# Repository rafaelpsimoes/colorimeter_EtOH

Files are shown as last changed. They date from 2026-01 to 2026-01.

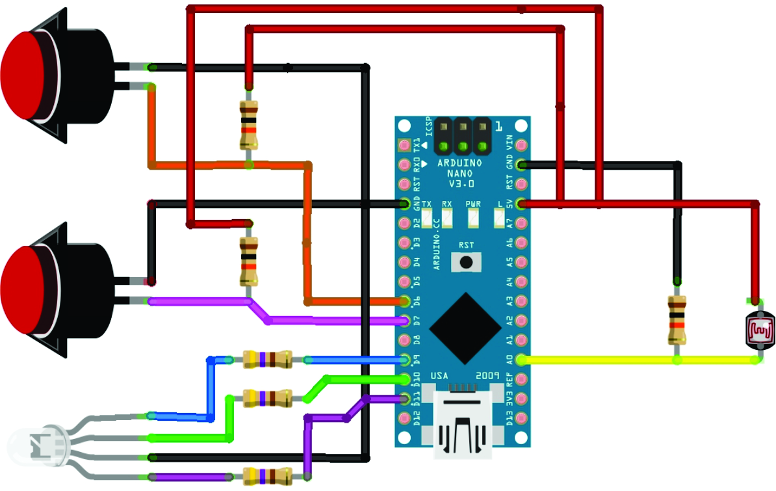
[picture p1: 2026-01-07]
hardware/schematics/schematic.jpg

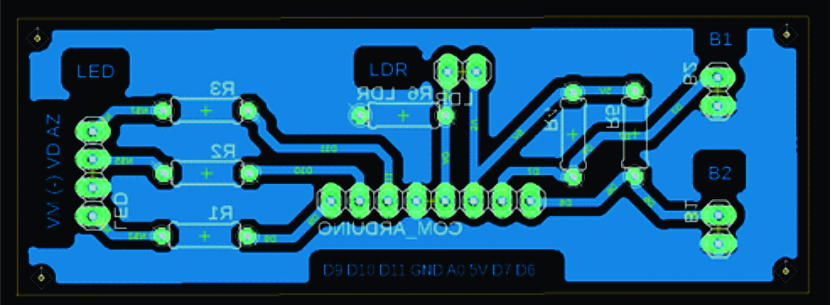
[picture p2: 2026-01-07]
hardware/pcb_eagle/eagle_mask.jpg

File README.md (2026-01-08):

# Low-Cost Portable Colorimeter for Indirect Ethanol Determination

This repository provides the complete set of hardware designs, firmware, and data-analysis scripts required to replicate the portable colorimeter described in the manuscript:

**Low-Cost Portable Colorimeter for Indirect Determination of Ethanol Concentration via Dichromate Oxidation**

The repository is intended to ensure **full reproducibility**, **methodological transparency**, and **low-cost accessibility**, in accordance with the scope and recommendations of *Hardware* (MDPI). All files necessary for device construction, operation, and data processing are made publicly available.

---

## Purpose and Scope

The proposed system is an open-hardware analytical device designed for indirect ethanol determination in aqueous solutions and simple beverage matrices. The instrument combines low-cost optical components, a microcontroller-based acquisition system, and open-source computational analysis to emulate spectrophotometric measurements in the visible range.

This repository supports:
- replication of the hardware design;
- execution of the firmware for data acquisition;
- processing of raw optical data into absorbance-like spectra;
- construction of calibration curves;
- estimation of ethanol concentration in unknown samples.

---

## Analytical Principle

Ethanol concentration is determined **indirectly** via its oxidation in acidic medium in the presence of potassium dichromate. The reduction of dichromate ions (Cr₂O₇²⁻) to Cr³⁺ produces a characteristic color change, with an absorption band centered around **595 nm**. Within the linear range of the method, the color intensity is proportional to the ethanol concentration.

**Important limitation:** the device does not measure ethanol directly. The analytical signal originates from the oxidation reaction products, and other oxidizable species may interfere depending on the sample matrix. This limitation is explicitly discussed in the associated manuscript.

---

## Repository Structure
├── hardware/  
│ ├── pcb_eagle/ # PCB layout designed using Autodesk Eagle (single-layer)  
│ ├── pcb_graphic/ # Alternative PCB mask with wider traces for ultra-low-cost fabrication  
│ ├── enclosure_stl/ # 3D-printable enclosure files (STL)  
│ └── schematics/ # Electronic schematics and wiring diagrams (PDF)  
│  
├── firmware/  
│ └── espec.ino # Arduino firmware for wavelength and transmittance acquisition  
│  
├── software/  
│ ├── etoh_concentrations.py # Calibration curve construction and spectral analysis  
│ ├── etoh_sample.py # Ethanol concentration estimation for unknown samples  
│ └── example_data/ # Example input files and formatting templates  
│  
├── documentation/  
│ └── assembly_guide # Device assembly illustrations  
│  
└── README.md  

---

## PCB Design Options and Fabrication Accessibility

Two functionally equivalent PCB layouts are provided to accommodate different fabrication constraints:

1. **Standard PCB layout (Eagle):**  
   Designed using Autodesk Eagle and optimized for compact integration and fabrication through conventional low-cost PCB manufacturing services.

2. **Graphic-mask PCB layout (wide traces):**  
   Developed using general-purpose graphic design software, featuring wider and more widely spaced conductive traces. This version facilitates ultra-low-cost fabrication approaches, such as manual toner transfer or direct printing, increasing robustness against fabrication defects.

Both PCB versions implement the same electronic circuit and were validated using the same experimental workflow.

---

## Operating Workflow Overview

### Step 1 — Sample Preparation
Prepare:
- a **blank solution** (0% ethanol), used as reference;
- ethanol standards covering the linear range of the method;
- unknown samples prepared according to the protocol described in the manuscript.

### Step 2 — Data Acquisition (Firmware)
1. Upload the firmware `firmware/espec.ino` to an Arduino-compatible board using the Arduino IDE.
2. Run the acquisition routine and open the Serial Monitor.
3. Copy the serial output (wavelength and transmittance values) and save it as plain text files.

### Step 3 — Required Input Files for Python Scripts

The Python scripts operate on plain text files containing wavelength–transmittance data:

- `ref.txt`  
  Reference measurement corresponding to the **blank (0% ethanol)**.

- Calibration files  
  One file per ethanol standard concentration (e.g., `0_5.txt`, `1_0.txt`, `1_5.txt`).

- Sample file(s)  
  Files corresponding to unknown samples (e.g., `sample_01.txt`).

Examples of correct file structure and formatting are provided in `software/example_data/`.

### Step 4 — Data Processing and Analysis
- `etoh_concentrations.py`  
  Converts transmittance to absorbance-like signals, performs spectral fitting, constructs calibration curves, and exports calibration parameters.

- `etoh_sample.py`  
  Applies calibration parameters to unknown samples and estimates ethanol concentration.

The scripts generate processed data tables and graphical outputs (spectra, calibration plots, and concentration results), consistent with the figures and tables presented in the manuscript.

---

## Validation and Performance

The portable colorimeter was validated by comparison with a commercial UV–Vis spectrophotometer. The results demonstrate linear calibration behavior (R² ≈ 0.99 within the tested range) and acceptable relative errors for alcoholic beverage samples analyzed under controlled conditions.

Detailed validation results and statistical analyses are presented in the associated publication.

---

## Safety Considerations

- Potassium dichromate and acidic solutions are hazardous chemicals.
- Appropriate personal protective equipment (PPE) must be used.
- Chromium-containing waste must be disposed of according to institutional and local regulations.

---

## Data and File Availability

All hardware designs, firmware, and software required to replicate the device and reproduce the experimental workflow are provided as supplementary materials and are available in this public repository:

**GitHub repository:** https://github.com/rafaelpsimoes/colorimeter_EtOH

---

## How to Cite

If you use this repository or any of its contents (hardware designs, firmware, or software), please cite the associated manuscript.  
A `CITATION.cff` file is included to facilitate citation export directly from GitHub.

---

## Intended Use

This repository is provided to support transparency, reproducibility, and academic use of the hardware and software described in the associated manuscript.

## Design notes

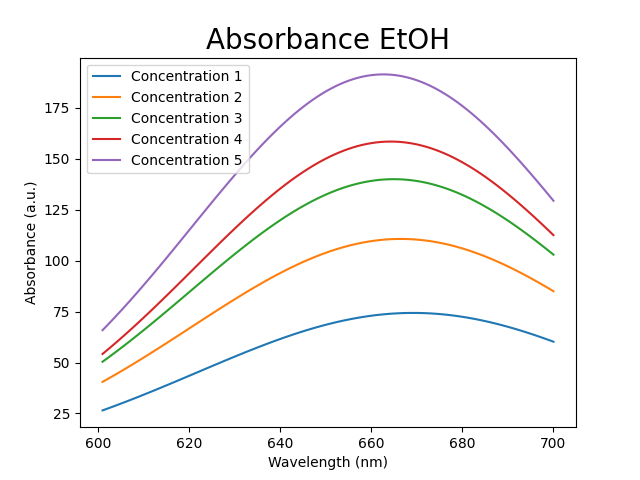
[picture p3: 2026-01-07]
software/example_data/absorbance_concentrations_clean.png

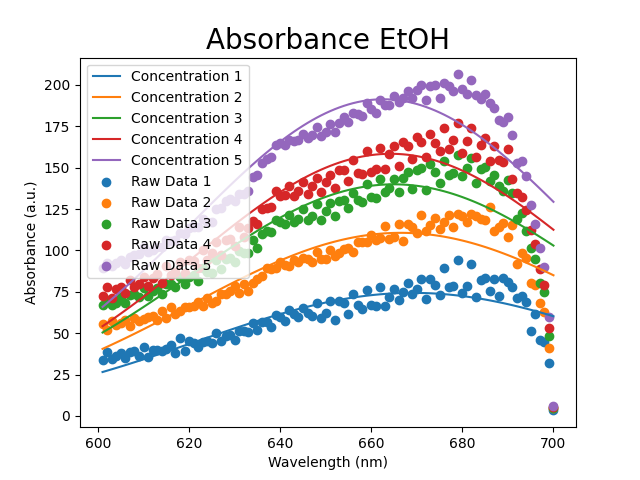
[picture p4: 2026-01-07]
software/example_data/absorbance_concentrations.png

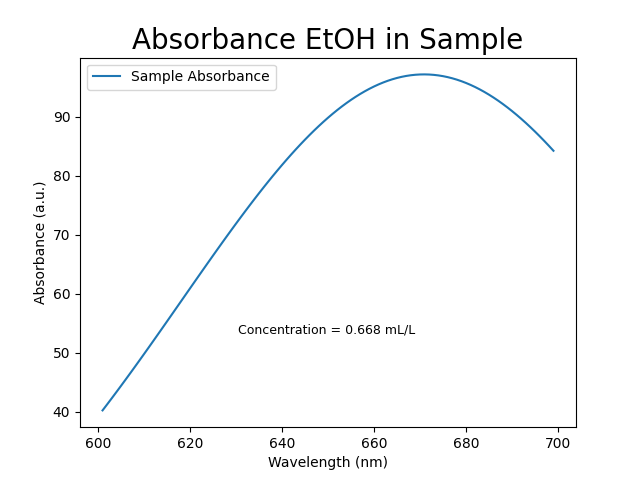
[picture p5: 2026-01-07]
software/example_data/absorbance_sample_vodka4.png

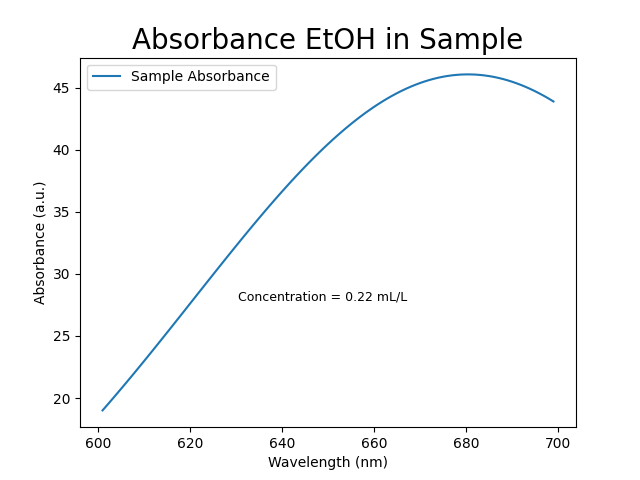
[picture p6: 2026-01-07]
software/example_data/absorbance_sample_vodka2.png

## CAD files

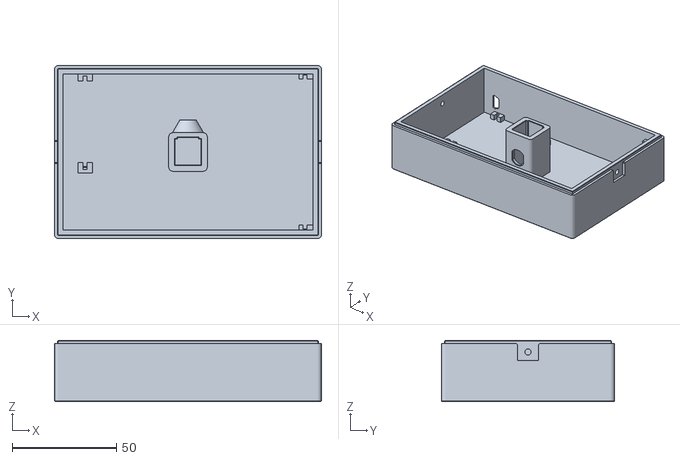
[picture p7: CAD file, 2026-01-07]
hardware/enclosure_stl/AL01.stl
128.0 x 83.0 x 29.2

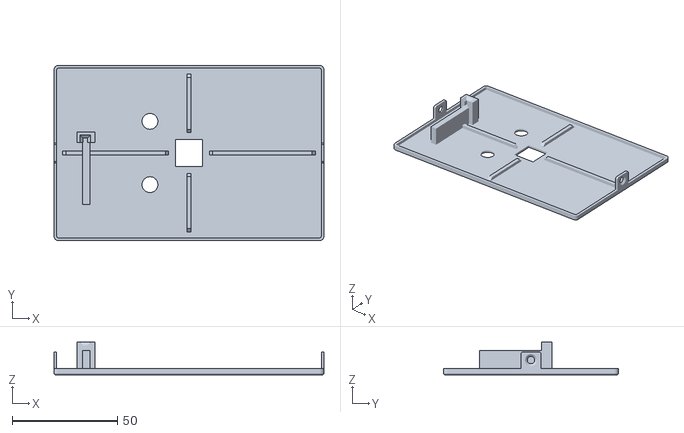
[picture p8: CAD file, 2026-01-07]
hardware/enclosure_stl/AL02.stl
128.0 x 83.0 x 15.4

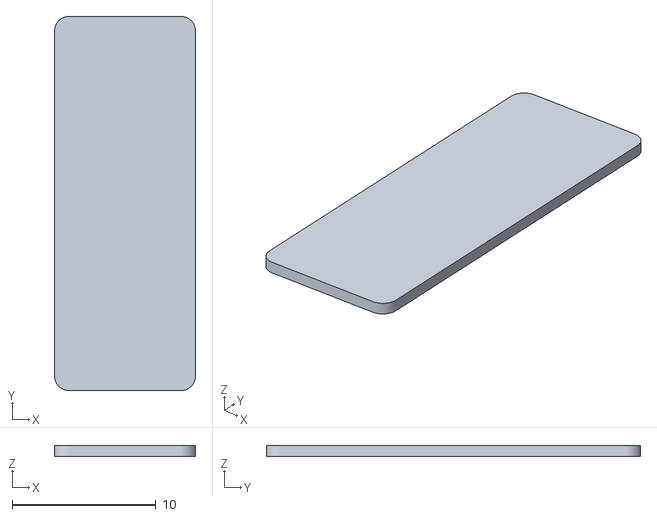
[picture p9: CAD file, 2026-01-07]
hardware/enclosure_stl/AL03.stl
9.80 x 26.0 x 0.75

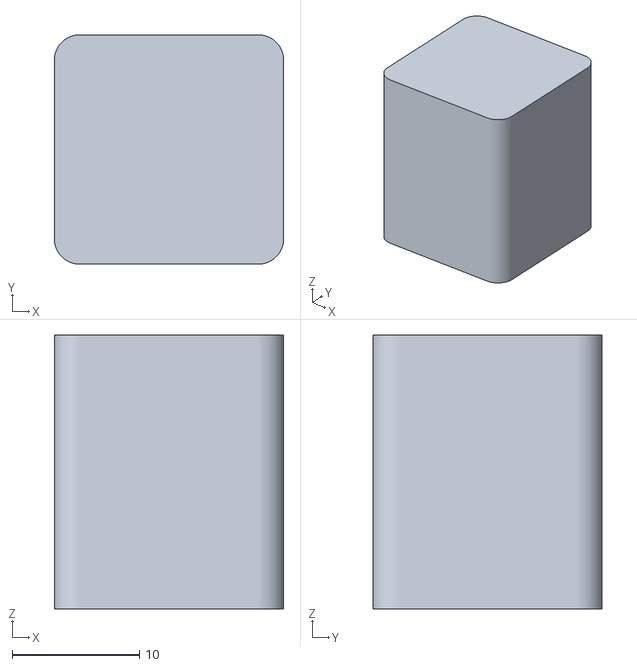
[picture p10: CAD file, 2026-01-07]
hardware/enclosure_stl/AL04.stl
18.0 x 18.0 x 21.5

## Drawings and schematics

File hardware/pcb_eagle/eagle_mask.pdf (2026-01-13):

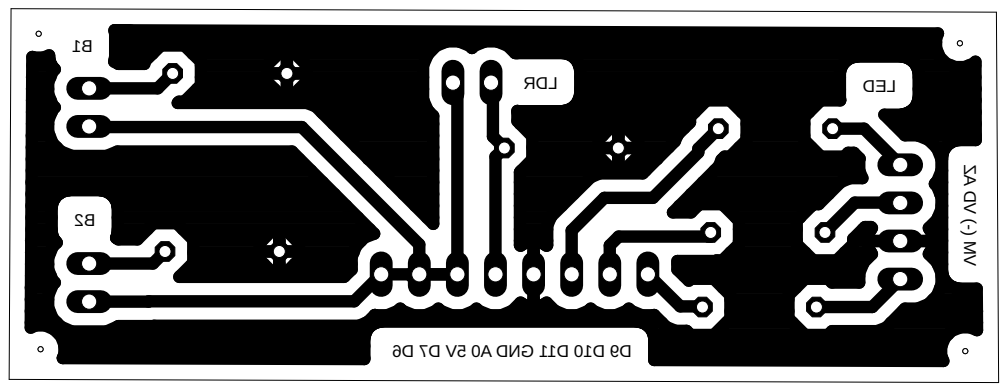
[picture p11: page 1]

6 D7 D V5 0A DNG11 D01 D9 D 1B2B RDL DEL VM (-) VD AZ

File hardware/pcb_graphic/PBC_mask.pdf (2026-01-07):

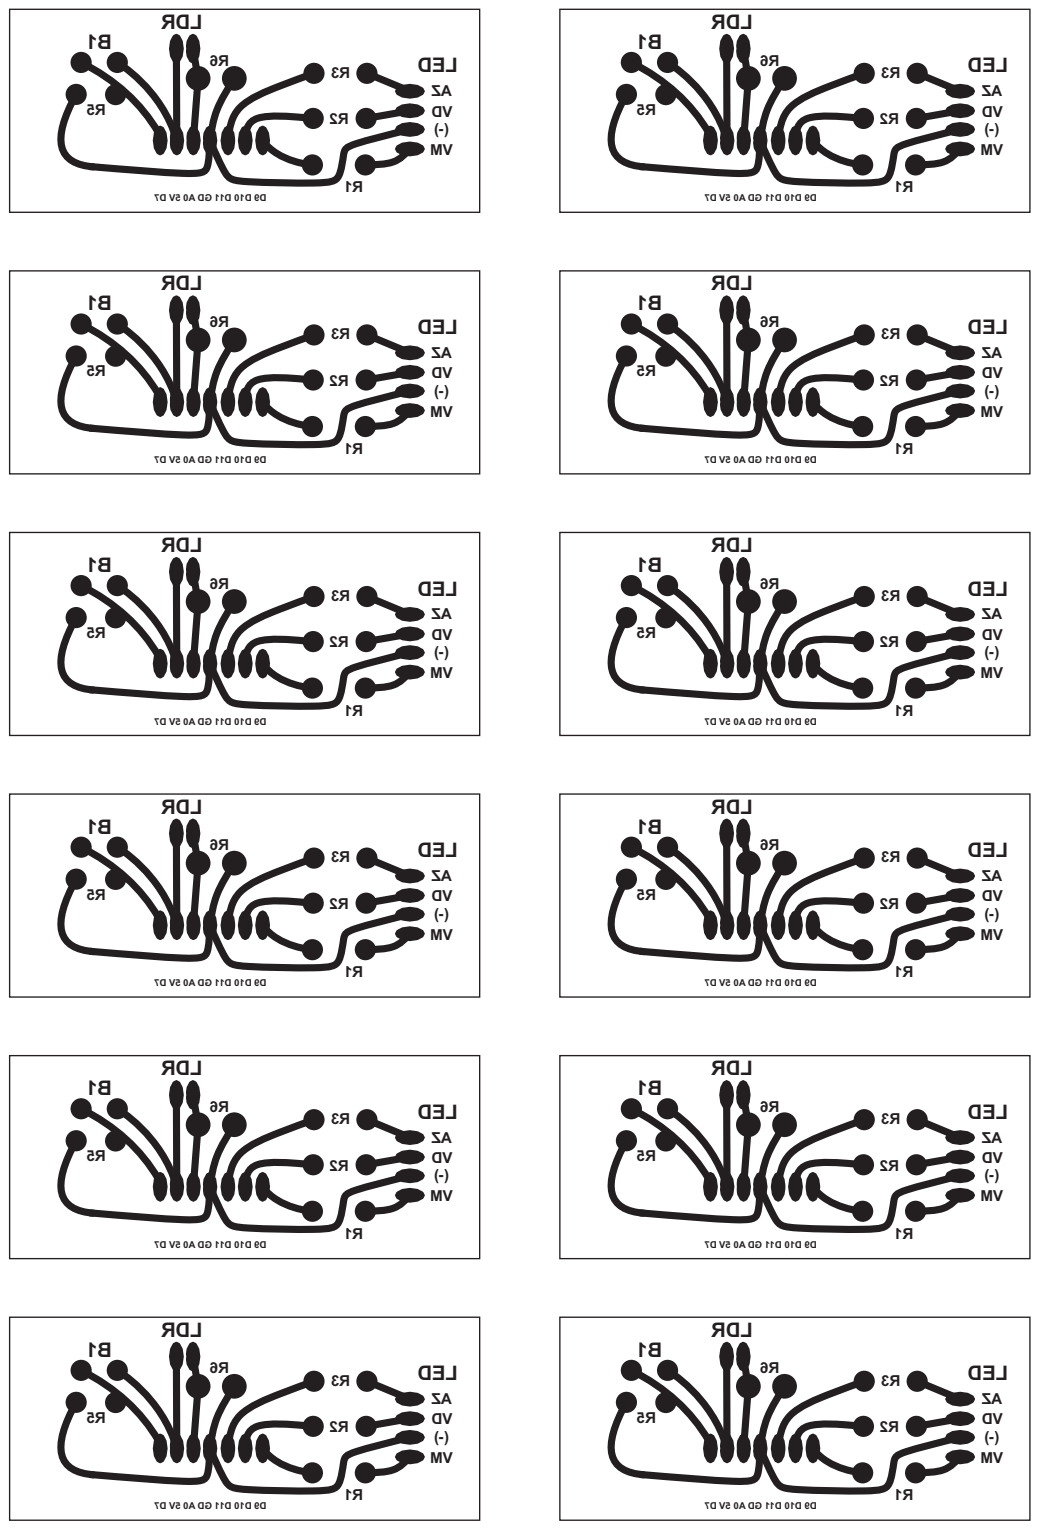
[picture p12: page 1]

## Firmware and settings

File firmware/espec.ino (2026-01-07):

//Script Spectrophotometer

//Arduino Ports
//D7: Push Button to start the scan
//D9: Blue LED
//D10: Green LED
//D11: Red LED

//Input Variables
//nscan: Number of scan

double r; //variable used to store the irradiance values for the red color
double g; //variable used to store the irradiance values for the green color
double b; //variable used to store the irradiance values for the blue color
double t; //parametric variable
int rr; //normalized irradiance output for red color
int gg; //normalized irradiance output for green color
int bb; //normalized irradiance output for blue color
int j; //auxiliar variable
int nscan = 10; //number of scans
double l; //wavelenght [400nm,700nm]
int photocell; //input values read on the LDR sensor
void setup ()
{
  Serial.begin(9600); //this value must be set for you computer
  pinMode (7, INPUT); //start button
  pinMode (9, OUTPUT); //blue LED
  pinMode (10, OUTPUT); //green LED
  pinMode (11, OUTPUT); //red LED
}
void loop () {
  if (digitalRead(7) == LOW) {
    {
      for (j = 1; j < (nscan + 1); j++) {
        for (l = 400; l < 701; l++) {
          r = 0.0;
          g = 0.0;
          b = 0.0;
          if ((l >= 400.0) && (l < 410.0)) {
            t = (l - 400.0) / (410.0 - 400.0);
            r = +(0.33 * t) - (0.20 * t * t);
          }
          else if ((l >= 410.0) && (l < 475.0)) {
            t = (l - 410.0) / (475.0 - 410.0);
            r = 0.14 - (0.13 * t * t);
          }
          else if ((l >= 545.0) && (l < 595.0)) {
            t = (l - 545.0) / (595.0 - 545.0);
            r = +(1.98 * t) - ( t * t);
          }
          else if ((l >= 595.0) && (l < 650.0)) {
            t = (l - 595.0) / (650.0 - 595.0);
            r = 0.98 + (0.06 * t) - (0.40 * t * t);
          }
          else if ((l >= 650.0) && (l < 700.0)) {
            t = (l - 650.0) / (700.0 - 650.0);
            r = 0.65 - (0.84 * t) + (0.20 * t * t);
          }
          if ((l >= 415.0) && (l < 475.0)) {
            t = (l - 415.0) / (475.0 - 415.0);
            g = +(0.80 * t * t);
          }
          else if ((l >= 475.0) && (l < 590.0)) {
            t = (l - 475.0) / (590.0 - 475.0);
            g = 0.8 + (0.76 * t) - (0.80 * t * t);
          }
          else if ((l >= 585.0) && (l < 639.0)) {
            t = (l - 585.0) / (639.0 - 585.0);
            g = 0.84 - (0.84 * t) ;
          }
          if ((l >= 400.0) && (l < 475.0)) {
            t = (l - 400.0) / (475.0 - 400.0);
            b = +(2.20 * t) - (1.50 * t * t);
          }
          else if ((l >= 475.0) && (l < 560.0)) {
            t = (l - 475.0) / (560.0 - 475.0);
            b = 0.7 - ( t) + (0.30 * t * t);
          }
          rr = r * 255;
          gg = g * 255;
          bb = b * 255;
          analogWrite(9, bb);
          analogWrite(10, gg);
          analogWrite(11, rr);
          delay(50);
          photocell = analogRead(0);
          Serial.print(int(l));
          Serial.print(",");
          Serial.println(photocell);
          delay(50);
        }
      }
    }
  }
}
